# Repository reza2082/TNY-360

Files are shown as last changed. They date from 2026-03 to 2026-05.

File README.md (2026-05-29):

Banner

<div align="center">

# TNY-360 Quadruped Robot





**A compact, open-source robot dog designed to *Understand*, *Interact*, and *Learn*.**

[🌐 Website](https://tny-robotics.com/tny-360) • [📸 Instagram](https://instagram.com/furwaz_) • [💬 Discord](https://discord.gg/XGABkx5A4y) • [📖 Documentation](https://tny-robotics.com/docs/tny-360/)

</div>

---

## 🚀 How to Build Your Own TNY-360

Everything you need to build this robot is 100% free and open-source. Instead of getting lost in the folders, we highly recommend following our official, step-by-step wiki:

<div align="center">

> ### **[👉 START HERE: The Official Step-by-Step Guide 👈](https://tny-robotics.com/docs/tny-360/practical-guide/sourcing)**
> *From ordering the first screw to the assembing the last part, this guide covers it all.*

</div>

### 🗂️ Quick Links (For Advanced Makers)
If you know what you are doing and just want the raw files, here is your toolkit:

* 🛒 **[Bill of Materials (BOM)](https://tny-robotics.com/docs/tny-360/practical-guide/1.sourcing/)** - What to buy, tools needed, and where to find them.
* 📐 **[CAD & 3D Files](./CAD)** - Grab the `.STL` and `.3MF` files for your 3D printer.
* ⚡ **[PCB Designs (Gerbers)](./Electronics/PCBs)** - Files to order the custom PCBs used in the robot.
* 🧠 **[ESP32 Firmware](./Firmware)** - The ESP-IDF C++ firmware & drivers powering the robot.
* 🛠️ **[Servo Modding Tutorial](https://tny-robotics.com/docs/tny-360/anatomy/electronics/mg996r-mod)** - Learn the Op-Amp trick to get position-feedback on MG996R servos.

## ✨ Features

* 🧬 **Dual-Core Architecture:**<br> A segregated system using the ESP32-S3. Core 0 ("Reflex") runs a strict 200Hz kinematics/control loop, while Core 1 ("Brain") handles WebSockets, UI, and orchestration.
* 🔄 **Closed-Loop at 200Hz:**<br> We ditched blind PWM. The TNY-360 uses digital MG996R servos modified with a custom **Op-Amp buffer PCB** for noise-free, high-speed position feedback.
* ⚡ **Zero Cable Spaghetti:**<br> A fully modular hardware ecosystem. Dedicated PCBs (Control, Sensor, Brain, Power, etc.) communicate cleanly via standardized JST-PH cables.
* 🛠️ **Smart Auto-Calibration:**<br> Features mechanical endstops for assembly validation and runtime algorithms that compensate for backlash and actuator latency.
* 🧩 **STEM & Expansion Ready:**<br> Program the robot using [TNY-Coder](https://github.com/TNY-Robotics/TNY-Coder) (our block-based web app) or build custom hardware modules using the dorsal I2C/Power expansion port.
* 🔋 **Industrial Power:**<br> A custom 3S 18650 battery pack capable of 15A continuous discharge, featuring an integrated BMS and Fuse, for 1h+ of runtime.

## 🧠 The Engineering: Beyond a Budget Robot

Most budget quadrupeds suffer from analog noise and jitter when hacking servos for feedback. Simply soldering a wire to a servo's internal potentiometer creates an antenna for EMI and draws current that destabilizes the servo's internal control loop.

**The TNY-360 Solution:** We designed a custom micro-PCB that fits inside the servo, featuring an **Operational Amplifier (Op-Amp) in a voltage follower (buffer) configuration**. 
This provides near-infinite input impedance (zero interference with the motor) and low output impedance to send a clean analog signal over the robot's wiring harness. Coupled with a software low-pass filter, the ESP32 can cleanly poll all 12 legs at 200Hz.

👉 **[Read the full technical deep-dive and the step-by-step Servo Modding Guide on our documentation site.](https://tny-robotics.com/docs/tny-360/anatomy/electronics/mg996r-mod)**

## ⚙️ Hardware Specs

### 🧠 Core & Power
* **MCU:** ESP32-S3 N16R8 Module
* **Power:** 3S LiPo Battery (6x Samsung INR18650-25R)
* **Monitoring:** INA219 (Voltage/Current sensor)

### 🦵 Actuators
* **Legs:** 12x MG996R Servos *(Must be modified for analog feedback)*
* **Head:** 2x SG-90 Micro Servos (Ears)
* **Driver:** PCA9685 (16-Channel PWM)

### 📡 Sensors & I/O
* **Vision:** OV2640 Camera Module
* **Distance:** VL53L0X Time-of-Flight (Lidar)
* **Orientation:** MPU6050 6-axis IMU
* **Display:** SH1106 OLED (128x64)
* **Audio:** I2S MEMS Microphone + Speaker

---

## 📂 Repository Structure

* `BOM/` — **Bill of Materials.** Detailed lists of all components, PCBs, screws, and cables, with links.
* `CAD/` — **Hardware Source.** FreeCAD project files and ready-to-print STLs.
* `Electronics/PCBs/` — **PCB Designs.** Gerber files, BOMs, and Pick'n'Place for all PCBs.
* `Firmware/` — **Codebase.** PlatformIO project (C++/ESP-IDF).
* `Firmware/components/` — **Drivers.** Custom libraries for sensors/actuators.

## 🤝 Contributing

We love contributions!
* **Code:** Please follow the ESP-IDF coding style.
* **Hardware:** Submit PRs with updated FreeCAD files or improvements.
* Found a bug? [Open an Issue](https://github.com/TNY-Robotics/TNY-360/issues).

## 📄 License & Authors

**TNY-360** is maintained by the [TNY Robotics Team](https://tny-robotics.com).

Licensed under **CC BY-NC-SA 4.0**.<br>
*You are free to share and adapt this material for non-commercial purposes, as long as you provide attribution and share alike.*



Need help? Contact us [by mail](mailto:contact@tny-robotics.com) or join our [Discord](https://discord.gg/XGABkx5A4y).

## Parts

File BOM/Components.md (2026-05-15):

# Components

Here's a list of all the components needed to build your TNY-360, and their links!

### Assembly guide

To learn how to fully assemble you TNY-360, check out the [TNY-360 Documentation](http://localhost:3000/docs/tny-360/practical-guide/sourcing/). A more user-friendly list of all the components needed is also available here. 

| Type | Description | Quantity | Location | Link |
| :--- | :--- | :---: | :--- | :--- |
| Step down | DC-DC 300W 20A Buck Converter | 1 | Torso Back | [Click here](https://s.click.aliexpress.com/e/_c3atP8dn) |
| Step down | DC-DC 5V 3A Converter | 1 | Mount PCB | [Click here](https://fr.aliexpress.com/item/1005008678729834.html) \[5V\] |
| | | | | |
| VL53L0X | Laser depth sensor | 1 | Visor | [Click here](https://s.click.aliexpress.com/e/_c4LPbeMT) \[0-200CM\] |
| SH1106 | OLED Screen 64x128 | 1 | Visor | [Click here](https://s.click.aliexpress.com/e/_c4POAdYX) \[WHITE\] |
| TTP223 | Touch sensor | 2 | Visor | [Click here](https://fr.aliexpress.com/item/1005006087171183.html) |
| OV2640 | HD Camera  120° 75mm | 1 | Visor | [Click here](https://s.click.aliexpress.com/e/_c3eXa4EP) \[120°/75mm\] |
| I2S Mic.  | I2S Microphone | 1 | Visor | [Click here](https://s.click.aliexpress.com/e/_c3CFAo5V) |
| Speaker | 2W 8Ω Speaker (25mm x 35mm) | 1 | Head | [Click here](https://fr.aliexpress.com/item/1005008626624201.html) \[5PCS 8Ω 2W\] |
| | | | | |
| SG90 | 0.9kg.cm servomotor | 2 | Head | [Click here](https://s.click.aliexpress.com/e/_c4PiVQKP) \[180°\] |
| MG996R | 12kg.cm servomotor | 12 | Torso / Legs | [Click here](https://s.click.aliexpress.com/e/_c3QXPU2f) \[180°\] |
| | | | | |
| MPU6050 | 6 axis accelerometer & gyroscope | 1 | Torso Center | [Click here](https://s.click.aliexpress.com/e/_c4LXGDrH) |
| Switches  | Tactile switches 6x6x5 mm | 4 | Feet | [Click here](https://s.click.aliexpress.com/e/_c4koO1EL) \[6x6x5mm\] |
| Antenna | Wi-Fi/Bluetooth 2.4Ghz antenna | 1 | Head | [Click here](https://s.click.aliexpress.com/e/_c3wCvBLz) \[FPC-IPX1/5cm] |

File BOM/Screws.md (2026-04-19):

# Screws & Inserts

Here's a list of all screws and inserts needed to build your TNY-360.

A complete kit of M2.5 Screws and Inserts is also linked below for easier sourcing, instead of buying each screws/inserts independently.

### Assembly guide

To learn how to fully assemble you TNY-360, check out the [TNY-360 Documentation](http://localhost:3000/docs/tny-360/practical-guide/sourcing/). A more user-friendly list of all the screws and inserts needed is also available here.

### Screws 

| Type | Length | Quantity | Location | Link |
| :--- | :----- | :---: | :--- | :---: |
| M1.4 | 5 mm | 32 | Shoulder & Knee Servo Disk  | [Click here](https://s.click.aliexpress.com/e/_c3CWv1Vp) |
| | | | | |
| M2.5 | 4 mm | 2 | Torso - PCB Motor Driver | [Click here](https://s.click.aliexpress.com/e/_c3p0AJO3) |
| M2.5 | 4 mm | 2 | Torso - PCB Analog Reader | [Click here](https://s.click.aliexpress.com/e/_c3p0AJO3) |
| M2.5 | 4 mm | 2 | Torso - PCB IMU | [Click here](https://s.click.aliexpress.com/e/_c3p0AJO3) |
| M2.5 | 4 mm | 2 | Torso - PCB Paw Boards | [Click here](https://s.click.aliexpress.com/e/_c3p0AJO3) |
| M2.5 | 4 mm | 4 | Torso - DC-DC Converter | [Click here](https://s.click.aliexpress.com/e/_c3p0AJO3) |
| M2.5 | 10 mm  | 12 | Torso - Top / Bottom screws | [Click here](https://s.click.aliexpress.com/e/_c3p0AJO3) |
| M2.5 | 6 mm | 4 | Torso - Front | [Click here](https://s.click.aliexpress.com/e/_c3p0AJO3) |
| M2.5 | 6 mm | 4 | Torso - Back | [Click here](https://s.click.aliexpress.com/e/_c3p0AJO3) |
| M2.5 | 6 mm | 4 | Torso - Battery | [Click here](https://s.click.aliexpress.com/e/_c3p0AJO3) |
| | | | | |
| M2.5 | 4 mm | 4 | Head - Top | [Click here](https://s.click.aliexpress.com/e/_c3p0AJO3) |
| M2.5 | 4 mm | 4 | Head - Bottom | [Click here](https://s.click.aliexpress.com/e/_c3p0AJO3) |
| M2.5 | 4 mm | 2 | Head - Face Plate | [Click here](https://s.click.aliexpress.com/e/_c3p0AJO3) |
| M2.5 | 4 mm | 4 | Head - PCB | [Click here](https://s.click.aliexpress.com/e/_c3p0AJO3) |
| | | | | |
| M2.5 | 6 mm | 8 | Shoulders - Top | [Click here](https://s.click.aliexpress.com/e/_c3p0AJO3) |
| M2.5 | 4 mm | 2 | Ears - Main Screw | [Click here](https://s.click.aliexpress.com/e/_c3p0AJO3) |
| M2.5 | 4 mm | 3 | Back - PCB | [Click here](https://s.click.aliexpress.com/e/_c3p0AJO3) |
| M2.5 | 4 mm | 4 | Back - Cover | [Click here](https://s.click.aliexpress.com/e/_c3p0AJO3) |
| | | | | |
| M2.5 | 6 mm | 4 | Mount - Cover | [Click here](https://s.click.aliexpress.com/e/_c3p0AJO3) |
| M2.5 | 6 mm | 4 | Mount - Attachment | [Click here](https://s.click.aliexpress.com/e/_c3p0AJO3) |
| M2.5 | 4 mm | 2 | Mount - PCB | [Click here](https://s.click.aliexpress.com/e/_c3p0AJO3) |
| | | | | |
| M2.5 | 4 mm | 6 | Battery - PCB | [Click here](https://s.click.aliexpress.com/e/_c3p0AJO3) |
| M2.5 | 4 mm | 6 | Battery - Cover | [Click here](https://s.click.aliexpress.com/e/_c3p0AJO3) |

### Inserts 

| Type | Length | Quantity | Location | Link |
| :--- | :----- | :---: | :--- | :---: |
| M2.5 | 2 mm | 2 | Torso - PCB Motor Driver | [Click here](https://fr.aliexpress.com/item/1005007653131713.html) |
| M2.5 | 2 mm | 2 | Torso - PCB Analog Reader | [Click here](https://fr.aliexpress.com/item/1005007653131713.html) |
| M2.5 | 2 mm | 2 | Torso - PCB IMU | [Click here](https://fr.aliexpress.com/item/1005007653131713.html) |
| M2.5 | 2 mm | 2 | Torso - PCB Paw Boards | [Click here](https://fr.aliexpress.com/item/1005007653131713.html) |
| M2.5 | 2 mm | 4 | Torso - DC-DC Converter | [Click here](https://fr.aliexpress.com/item/1005007653131713.html) |
| M2.5 | 6 mm | 12 | Torso - Top / Bottom screws | [Click here](https://fr.aliexpress.com/item/1005007653131713.html) |
| M2.5 | 4 mm | 4 | Torso - Front | [Click here](https://fr.aliexpress.com/item/1005007653131713.html) |
| M2.5 | 4 mm | 4 | Torso - Back | [Click here](https://fr.aliexpress.com/item/1005007653131713.html) |
| M2.5 | 2 mm | 4 | Torso - Battery | [Click here](https://fr.aliexpress.com/item/1005007653131713.html) |
| | | | | |
| M2.5 | 2 mm | 4 | Head - Top | [Click here](https://fr.aliexpress.com/item/1005007653131713.html) |
| M2.5 | 2 mm | 4 | Head - Bottom | [Click here](https://fr.aliexpress.com/item/1005007653131713.html) |
| M2.5 | 2 mm | 2 | Head - Face Plate | [Click here](https://fr.aliexpress.com/item/1005007653131713.html) |
| M2.5 | 2 mm | 4 | Head - PCB | [Click here](https://fr.aliexpress.com/item/1005007653131713.html) |
| | | | | |
| M2.5 | 2 mm | 8 | Shoulders - Top | [Click here](https://fr.aliexpress.com/item/1005007653131713.html) |
| M2.5 | 2 mm | 2 | Ears - Main Screw | [Click here](https://fr.aliexpress.com/item/1005007653131713.html) |
| M2.5 | 2 mm | 3 | Back - PCB | [Click here](https://fr.aliexpress.com/item/1005007653131713.html) |
| M2.5 | 2 mm | 4 | Back - Cover | [Click here](https://fr.aliexpress.com/item/1005007653131713.html) |
| | | | | |
| M2.5 | 4 mm | 4 | Mount - Cover | [Click here](https://fr.aliexpress.com/item/1005007653131713.html) |
| M2.5 | 4 mm | 4 | Mount - Attachment | [Click here](https://fr.aliexpress.com/item/1005007653131713.html) |
| M2.5 | 2 mm | 2 | Mount - PCB | [Click here](https://fr.aliexpress.com/item/1005007653131713.html) |
| | | | | |
| M2.5 | 2 mm | 6 | Battery - PCB | [Click here](https://fr.aliexpress.com/item/1005007653131713.html) |
| M2.5 | 2 mm | 6 | Battery - Cover | [Click here](https://fr.aliexpress.com/item/1005007653131713.html) |

### Total 

| Type | Quantity | Link |
| :--- | :---: | --- |
| M1.4 Screw - 5 mm  | 32 | [Click here](https://s.click.aliexpress.com/e/_c3CWv1Vp) |
| | | |
| M2.5 Screw - 4 mm  | 49 | [Click here](https://s.click.aliexpress.com/e/_c3p0AJO3) |
| M2.5 Screw - 6 mm  | 28 | [Click here](https://s.click.aliexpress.com/e/_c3p0AJO3) |
| M2.5 Screw - 10 mm | 12 | [Click here](https://s.click.aliexpress.com/e/_c3p0AJO3) |
| | | |
| M2.5 Insert - 2 mm | 61 | [Click here](https://fr.aliexpress.com/item/1005007653131713.html) |
| M2.5 Insert - 4 mm | 16 | [Click here](https://fr.aliexpress.com/item/1005007653131713.html) |
| M2.5 Insert - 6 mm | 12 | [Click here](https://fr.aliexpress.com/item/1005007653131713.html) |

### Complete kit

To simplify Screws and Inserts sourcing, you can alternatively buy only one complete kit of M2.5 screws and inserts.

* Link to the [Screws / Inserts Kit](https://fr.aliexpress.com/item/1005007830491580.html).

Please check that you selected the `M2.5 500pcs` version before ordering.

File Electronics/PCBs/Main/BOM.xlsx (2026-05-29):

No. | Quantity | Comment | Designator | Footprint | Value | Manufacturer Part | Manufacturer | Supplier Part | Supplier
1 | 1 | XL-5050RGBC-2812B | 2812B | LED-SMD_4P-L5.0-W5.0-BL_XL-5050RGBC |  | XL-5050RGBC-2812B | XINGLIGHT(成兴光) | C2843785 | LCSC
2 | 2 | AMS1117-3.3 | AMS3.3,AMS3.3ESP | SOT-223-3_L6.5-W3.4-P2.30-LS7.0-BR |  | AMS1117-3.3 | AMS | C6186 | LCSC
3 | 2 | B3B-PH-K-S(LF)(SN) | BTN_LEFT,BTN_RIGHT | CONN-TH_B3B-PH-K-S |  | B3B-PH-K-S(LF)(SN) | JST | C131339 | LCSC
4 | 1 | HX 0.5-24PIN XGXJ-H2.0 | CAM | FPC-SMD_24P-P0.50_HX-0.5-24PIN-XGXJ-H2.0 |  | HX 0.5-24PIN XGXJ-H2.0 | hanxia(韩下) | C19269981 | LCSC
5 | 3 | 220pF | CASIG,CSPKRG,CSPKRV | C0603 | 220pF | CL10B221KB8NNNC | SAMSUNG(三星) | C1603 | LCSC
6 | 4 | 10uF | CAVDD2,CCH340,CDVDD2,CESP2 | C0603 | 10uF | CL10A106MA8NRNC | SAMSUNG(三星) | C96446 | LCSC
7 | 8 | 100nF | CAVDD,CAVDD1,CCAM14,CCSI_RST,CDVDD1,CESP1,CINL,CSPKR | C0603 | 100nF | CC0603KRX7R9BB104 | YAGEO(国巨) | C14663 | LCSC
8 | 1 | 15pF | CCAM8 | C0603 | 15pF | CL10C150JB8NNNC | SAMSUNG(三星) | C1644 | LCSC
9 | 1 | CH340C | CH340C | SOP-16_L10.0-W3.9-P1.27-LS6.0-BL |  | CH340C | WCH(南京沁恒) | C84681 | LCSC
10 | 3 | 1uF | CINR1,CUPEN1,CVREF | C0603 | 1uF | CL10A105KO8NNNC | SAMSUNG(三星) | C1592 | LCSC
11 | 1 | 10nF | CINR2 | C0603 | 10nF | 0603B103K500NT | FH(风华) | C57112 | LCSC
12 | 4 | B4B-PH-K-S(LF)(SN) | CN-BAT,CN-IMU,CN-LASER,CN-SCREEN | CONN-TH_B4B-PH-K-S |  | B4B-PH-K-S(LF)(SN) | JST | C131334 | LCSC
13 | 2 | B5B-PH-K-S(LF)(SN) | CN-MOTORS,MIC | CONN-TH_B5B-PH-K-S-LF-SN |  | B5B-PH-K-S(LF)(SN) | JST | C157993 | LCSC
14 | 1 | B2B-PH-K-S(LF)(SN) | CN-POWER | CONN-TH_B2B-PH-K-S |  | B2B-PH-K-S(LF)(SN) | JST | C131337 | LCSC
15 | 1 | B7B-PH-K-S(LF)(SN) | CN-READER | CONN-TH_B7B-PH-K-S-LF-SN |  | B7B-PH-K-S(LF)(SN) | JST | C157981 | LCSC
16 | 1 | 470uF | CPGND | CAP-TH_BD8.0-P3.50-D0.6-FD | 470uF | GR477M025F14RR0VL4FP0 | Chengx(承兴) | C5154 | LCSC
17 | 2 | SS34 | D1,D2 | SMA_L4.3-W2.6-LS5.2-RD |  | SS34 | MDD(辰达半导体) | C8678 | LCSC
18 | 1 | SMAJ5.0A | D3 | SMA_L4.3-W2.6-LS5.2-RD |  | SMAJ5.0A | RUILON(瑞隆源) | C10758 | LCSC
19 | 1 | ESP32-S3-WROOM-1U-N16R8 | ESP32-S3 | WIRELM-SMD_ESP32-S3-WROOM-1U |  | ESP32-S3-WROOM-1U-N16R8 | ESPRESSIF(乐鑫) | C3013946 | LCSC
20 | 1 | SMD1812P150TF/16 | F1 | F1812 |  | SMD1812P150TF/16 | RUILON(瑞隆源) | C20810 | LCSC
21 | 3 | BLM18SG121TN1D | LAVDD,LSPKRG,LSPKRV | L0603 |  | BLM18SG121TN1D | muRata(村田) | C113030 | LCSC
22 | 1 | PAM8406DR | PAM8406 | SOIC-16_L9.9-W3.9-P1.27-LS6.0-BL |  | PAM8406DR | DIODES(美台) | C86270 | LCSC
23 | 2 | S8050 J3Y(RANGE:200-350) | QDTR,QRTS | SOT-23-3_L3.0-W1.7-P0.95-LS2.9-BR |  | S8050 J3Y(RANGE:200-350) | CJ(江苏长电/长晶) | C2146 | LCSC
24 | 2 | 1kΩ | RCAM17,RINR | R0603 | 1kΩ | RC0603FR-071KL | YAGEO(国巨) | C22548 | LCSC
25 | 3 | 10kΩ | RDTR,RRTS,RUPEN1 | R0603 | 10kΩ | 0603WAF1002T5E | UNI-ROYAL(厚声) | C25804 | LCSC
26 | 1 | 22kΩ | RPAM | R0603 | 22kΩ | 0603WAF2202T5E | UNI-ROYAL(厚声) | C31850 | LCSC
27 | 1 | 4.7kΩ | RRST | R0603 | 4.7kΩ | 0603WAF4701T5E | UNI-ROYAL(厚声) | C23162 | LCSC
28 | 4 | 2.2kΩ | RUPFA,RUPFL,RUPSA,RUPSL | R0603 | 2.2kΩ | 0603WAF2201T5E | UNI-ROYAL(厚声) | C4190 | LCSC
29 | 1 | 1.25mm-2P ZZ-MS | SPEAKER | CONN-TH_2P-P1.25_1.25MM-2P-ZZ-MS |  | 1.25mm-2P ZZ-MS | SHOU HAN(首韩) | C5368706 | LCSC
30 | 1 | TYPE-C16PIN | USB | USB-C-SMD_TYPE-C16PIN |  | TYPE-C16PIN | SHOU HAN(首韩) | C393939 | LCSC
31 | 1 | USBLC6-2SC6 | USBLC6 | SOT-23-6_L2.9-W1.6-P0.95-LS2.8-BL |  | USBLC6-2SC6 | ST(意法半导体) | C7519 | LCSC
32 | 1 | XC6206-1.2V | XC6206-1.2 | SOT-23-3_L3.0-W1.6-P1.90-LS2.8-BR |  | XC6206-1.2V | YONGYUTAI(永裕泰) | C49446790 | LCSC
33 | 1 | XC6206-2.8V | XC6206-2.8 | SOT-23-3_L2.9-W1.6-P1.90-LS2.8-BR |  | XC6206-2.8V | YONGYUTAI(永裕泰) | C2892669 | LCSC

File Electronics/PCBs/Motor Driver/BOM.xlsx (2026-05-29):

No. | Quantity | Comment | Designator | Footprint | Value | Manufacturer Part | Manufacturer | Supplier Part | Supplier
1 | 2 | 100nF | C-LS,C-PCA | C0805 | 100nF | CC0805KRX7R9BB104 | YAGEO(国巨) | C49678 | LCSC
2 | 4 | B3B-PH-K-S(LF)(SN) | CN-BL,CN-BR,CN-FL,CN-FR | CONN-TH_B3B-PH-K-S |  | B3B-PH-K-S(LF)(SN) | JST | C131339 | LCSC
3 | 1 | B5B-PH-K-S(LF)(SN) | CN-SIGNAL | CONN-TH_B5B-PH-K-S-LF-SN |  | B5B-PH-K-S(LF)(SN) | JST | C157993 | LCSC
4 | 1 | PCA9306DCUR | PCA9306 | SSOP-8_L2.0-W2.3-P0.50-LS3.1-BR |  | PCA9306DCUR | TI(德州仪器) | C33196 | LCSC
5 | 1 | PCA9685PW,118 | PCA9685 | TSSOP-28_L9.7-W4.4-P0.65-LS6.4-TL | - | PCA9685PW,118 | NXP(恩智浦) | C2678753 | LCSC
6 | 14 | 220Ω | R1,R2,R3,R4,R5,R6,R7,R8,R9,R10,R11,R12,R13,R14 | R0805 | 220Ω | 0805W8F2200T5E | UNI-ROYAL(厚声) | C17557 | LCSC
7 | 1 | 200kΩ | R-LS | R0805 | 200kΩ | 0805W8F2003T5E | UNI-ROYAL(厚声) | C17539 | LCSC
8 | 2 | 2.2kΩ | RUP1,RUP2 | R0805 | 2.2kΩ | 0805W8F2201T5E | UNI-ROYAL(厚声) | C17520 | LCSC

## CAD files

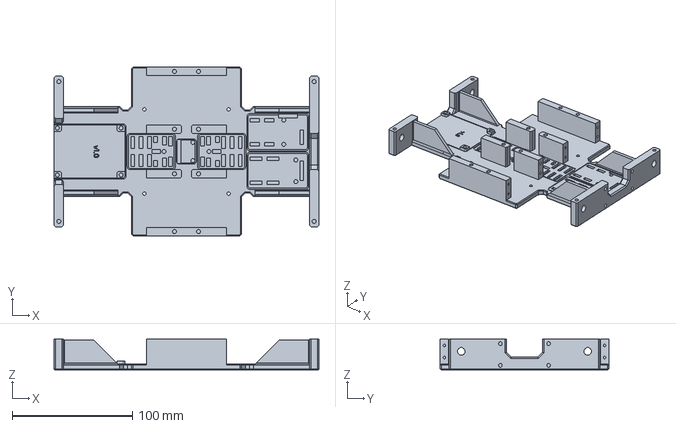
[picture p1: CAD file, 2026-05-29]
CAD/01_Parts/Torso.FCStd
220.0 x 140.0 x 25.7 mm

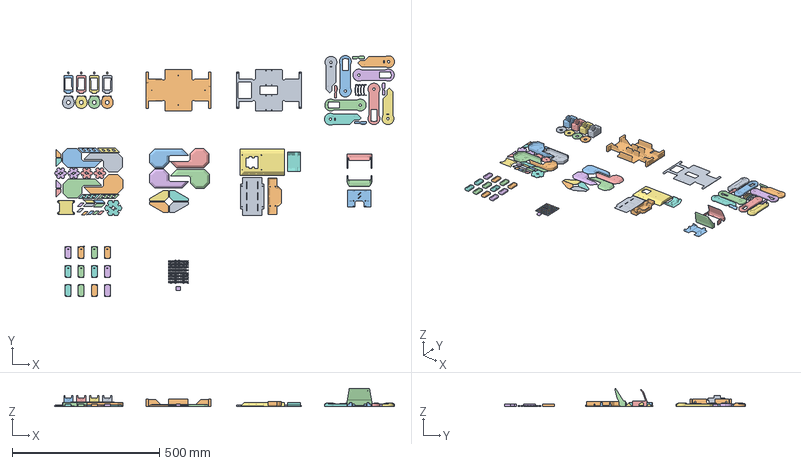
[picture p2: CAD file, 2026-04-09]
CAD/Exported/TNY-360.3mf
1152.9 x 816.7 x 62.4 mm
Shoulder - BL.stl
Servo - Cover Top.stl x 8
Clip.stl x 72
Shoulder - BR.stl
Shoulder - FL.stl
Servo - Cover Right.stl x 2
Shoulder - FR.stl
Servo - Cover Left.stl x 2
Shoulder - Top.stl x 4
Shoulder - Pin.stl x 4
Torso - Top.stl
Torso - Bottom.stl
Leg - Top BL.stl
Leg - Top BR.stl
Leg - Top FL.stl
Leg - Top FR.stl
Leg - Bottom L.stl x 2
Leg - Bottom R.stl x 2
Leg - Top Cover Top L.stl x 2
Leg - Top Cover Top R.stl x 2
Leg - Bottom L - Cover.stl x 2
Leg - Bottom R - Cover.stl x 2
Leg - Top Cover Bottom L.stl x 2
Leg - Top Cover Bottom R.stl x 2
Leg - Top Cover Logo L.stl x 2
Leg - Top Cover Logo R.stl x 2
Leg - Top Cover Stripes L.stl x 2
Leg - Top Cover Stripes R.stl x 2
Leg - Bottom L - Cover Black 1.stl x 2
Leg - Bottom L - Cover Black 2.stl x 2
Leg - Bottom R - Cover Black 1.stl x 2
Leg - Bottom R - Cover Black 2.stl x 2
Torso - Cover.stl
Torso - Cover Logo.stl
Torso - Cover Wing.stl x 6
Torso - Cover Attach.stl
Back - Bottom Clip.stl
Battery - LipoHolder Base.stl
Back - Cover.stl
Head - Backplate.stl
Head - Bottom Cover.stl
Head - Top Cover.stl
Clip - Helper.stl
Leg - Top Wire holder.stl x 4
Leg - Top Wire Holder L.stl x 2
Leg - Top Wire Holder R.stl x 2

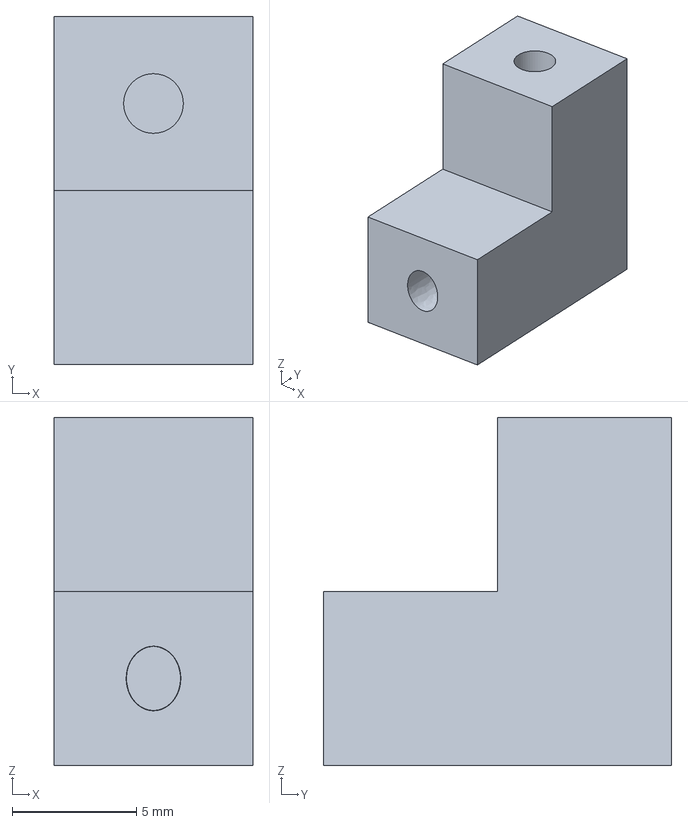
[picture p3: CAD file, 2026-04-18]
CAD/Settings.FCStd
8.00 x 14.0 x 14.0 mm

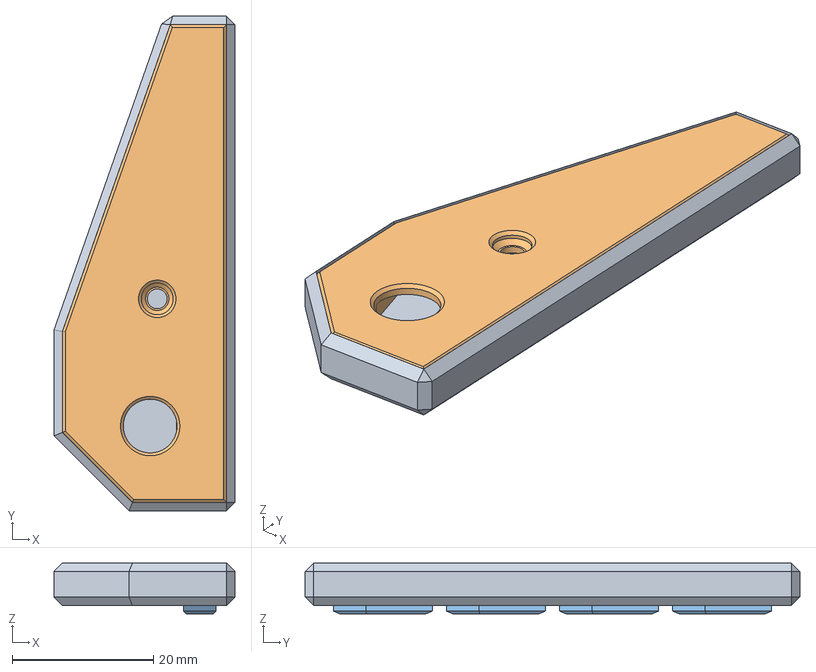
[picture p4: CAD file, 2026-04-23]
CAD/01_Parts/Ears.FCStd
25.6 x 70.0 x 7.20 mm
Front - L
Back - L
Deco - L

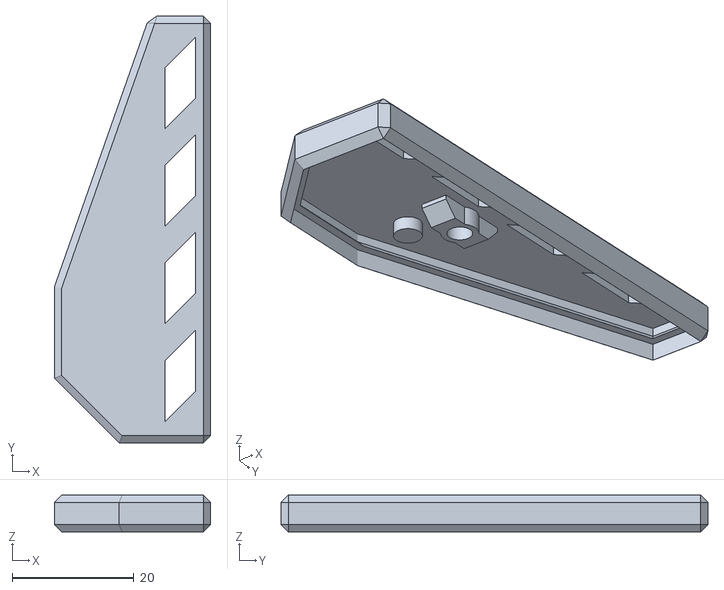
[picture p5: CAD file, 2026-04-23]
CAD/Exported/STLs/Ears - Front R.stl
25.6 x 70.0 x 6.00

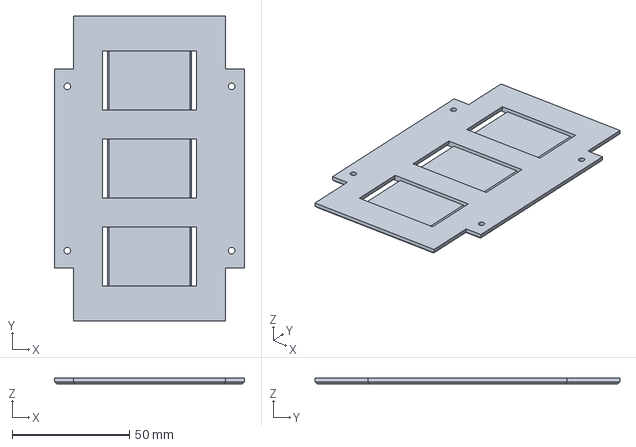
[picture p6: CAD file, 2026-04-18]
CAD/01_Parts/Battery.FCStd
81.0 x 130.0 x 2.40 mm

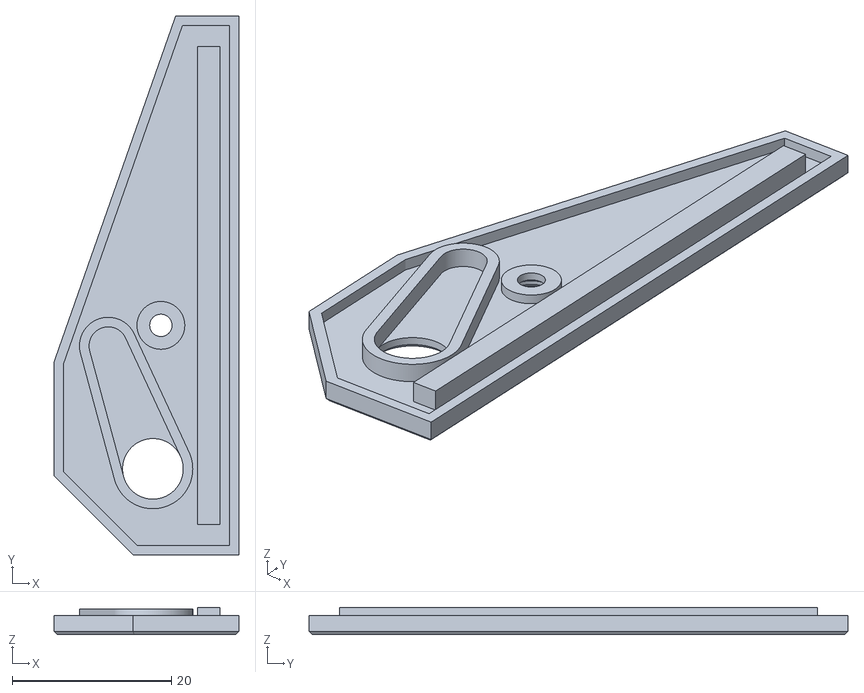
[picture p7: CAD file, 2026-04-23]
CAD/Exported/STLs/Ears - Back R.stl
23.2 x 67.6 x 3.40

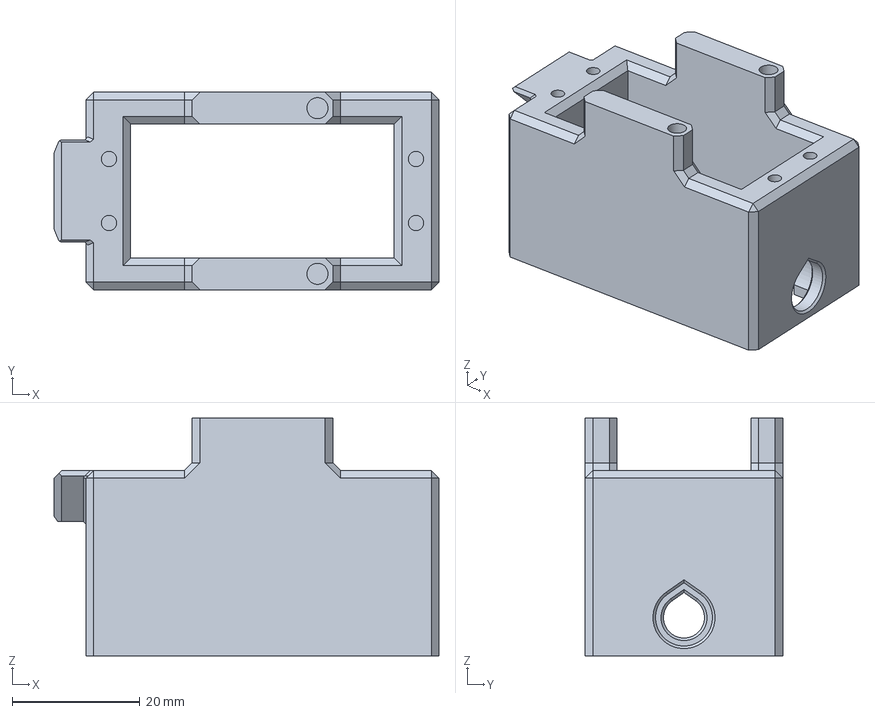
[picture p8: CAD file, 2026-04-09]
CAD/01_Parts/Shoulders.FCStd
60.2 x 30.9 x 37.2 mm

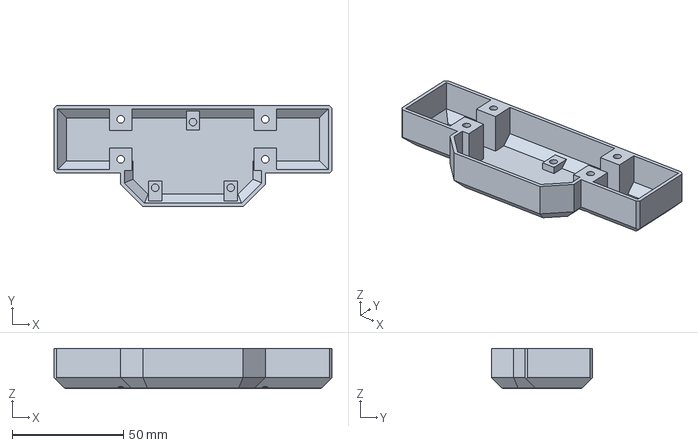
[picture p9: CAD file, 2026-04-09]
CAD/01_Parts/Back.FCStd
125.0 x 45.5 x 18.1 mm

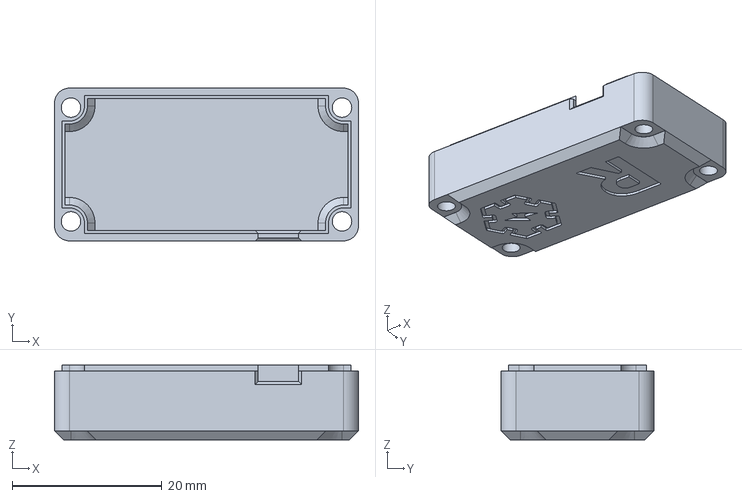
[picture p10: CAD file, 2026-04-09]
CAD/01_Parts/Servo_Cover.FCStd
40.6 x 20.4 x 10.0 mm

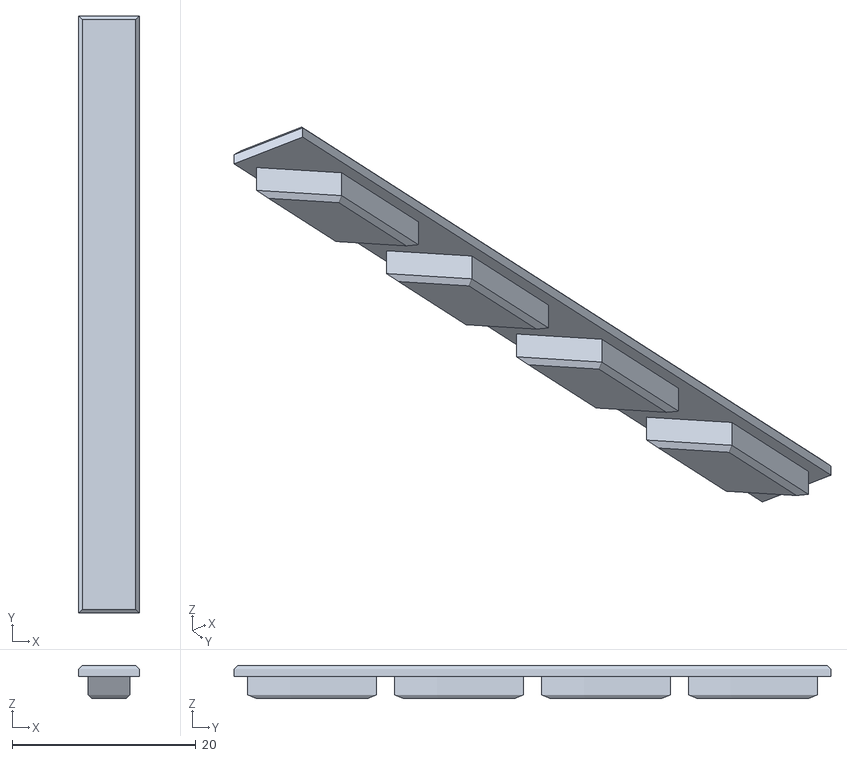
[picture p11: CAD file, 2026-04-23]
CAD/Exported/STLs/Ears - Deco L.stl
6.60 x 65.0 x 3.60

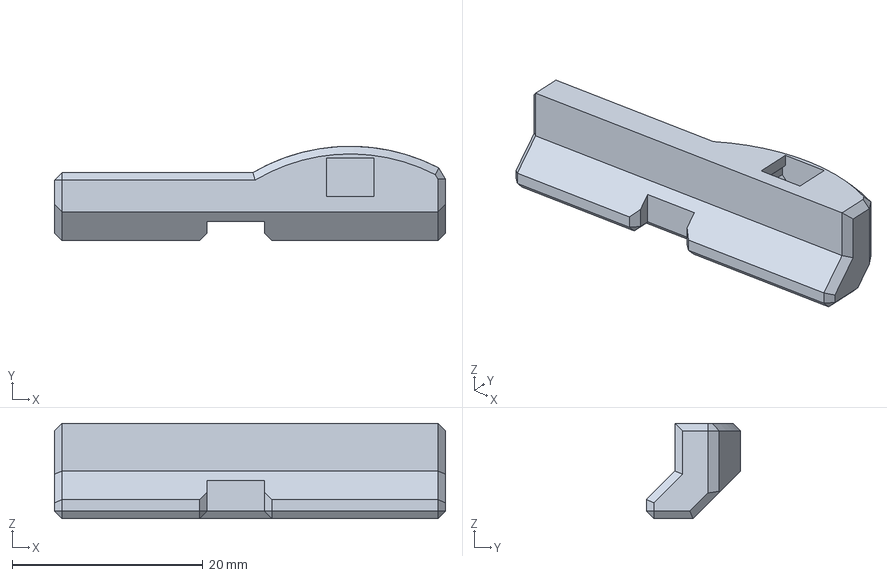
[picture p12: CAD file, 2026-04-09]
CAD/01_Parts/Leg_Top.FCStd
41.0 x 9.90 x 10.0 mm

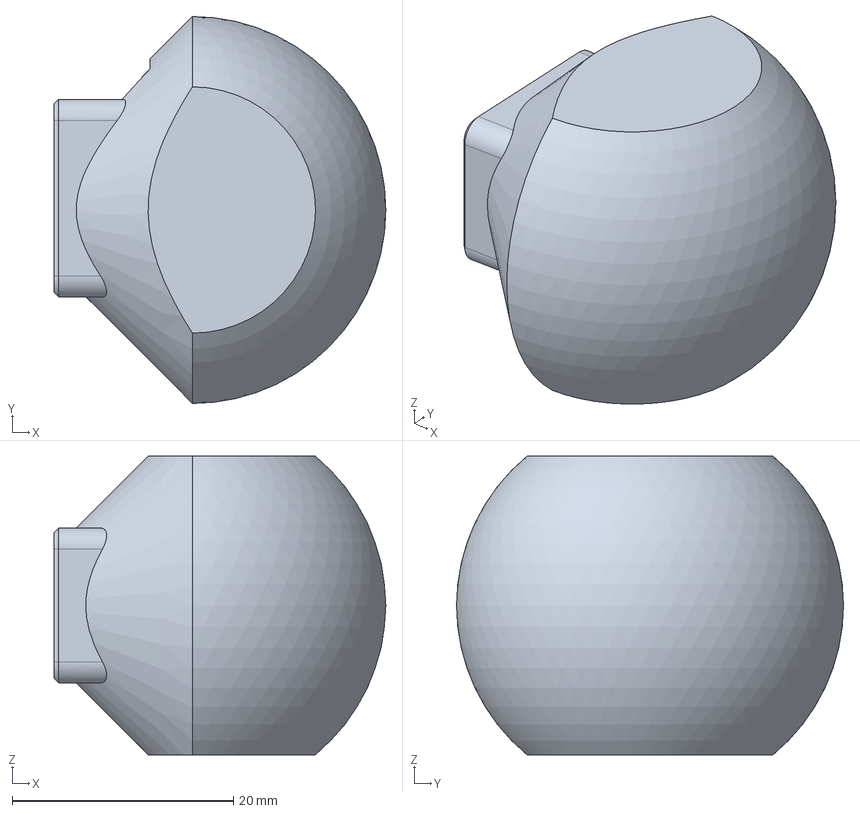
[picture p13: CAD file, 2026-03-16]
CAD/01_Parts/Leg_Bottom.FCStd
30.0 x 35.0 x 27.0 mm

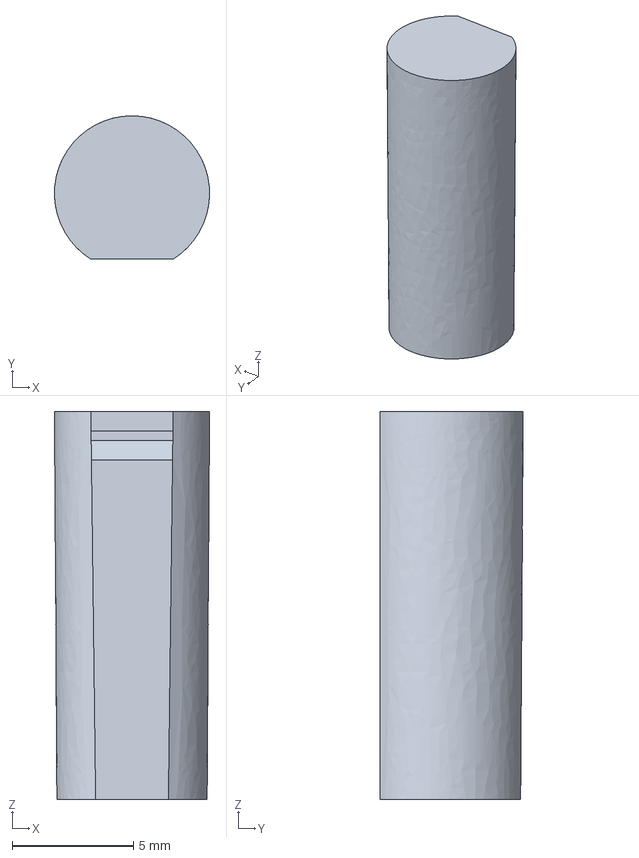
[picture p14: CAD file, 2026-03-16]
CAD/01_Parts/Torso-Shoulder_Pin.FCStd
6.40 x 5.91 x 16.0 mm

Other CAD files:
CAD/Exported/STLs/Torso - Bottom.stl
CAD/Exported/STLs/Ears - Back L.stl
CAD/Exported/STLs/Ears - Front L.stl
CAD/Exported/STLs/Ears - Deco R.stl
CAD/Exported/STLs/Settings - ServoScrew.stl

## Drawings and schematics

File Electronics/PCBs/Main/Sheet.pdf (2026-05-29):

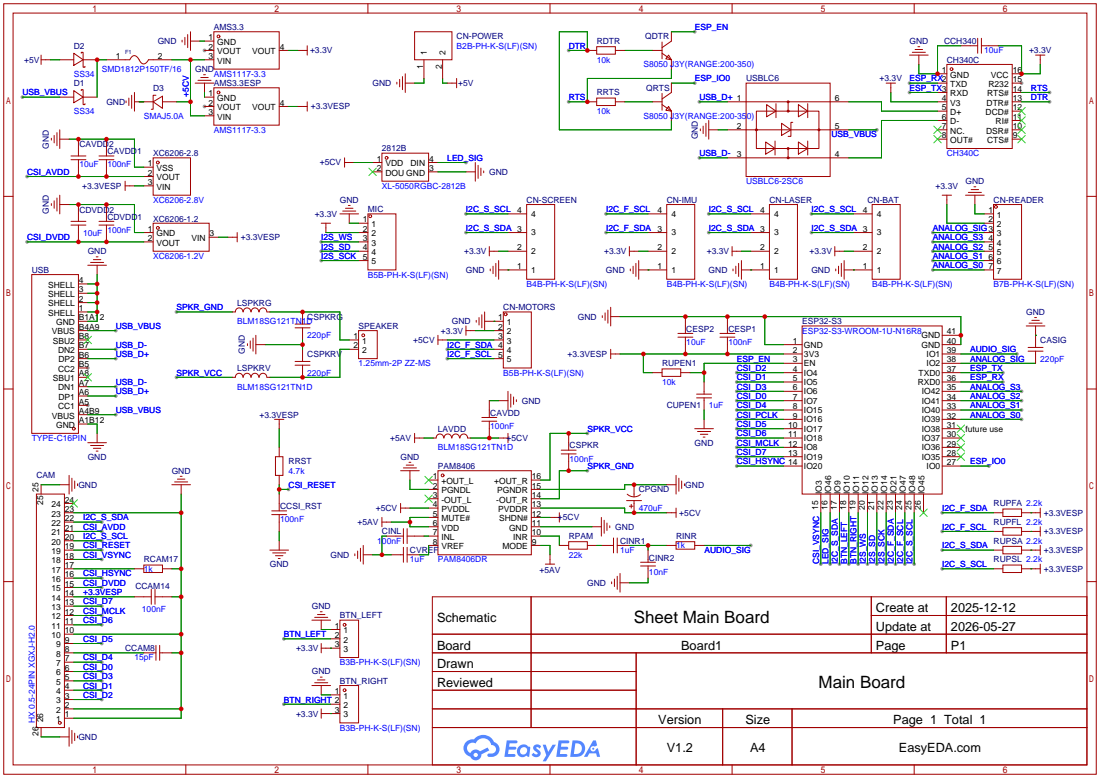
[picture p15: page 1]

DSR# 10 RI# 11 DCD# 12 DTR# 13 RTS# 14 R232 15 VCC 16

INR 10 GND 11 SHDN# 12 PVDDR 13 -OUT_R 14 PGNDR 15 +OUT_R 16

Schematic | Sheet Main Board | Create at | 2025-12-12

Update at | 2026-05-27

Board | Board1 | Page | P1
Drawn | | Main Board
Reviewed

Version | Size | Page 1 Total 1
V1.2 | A4 | EasyEDA.com

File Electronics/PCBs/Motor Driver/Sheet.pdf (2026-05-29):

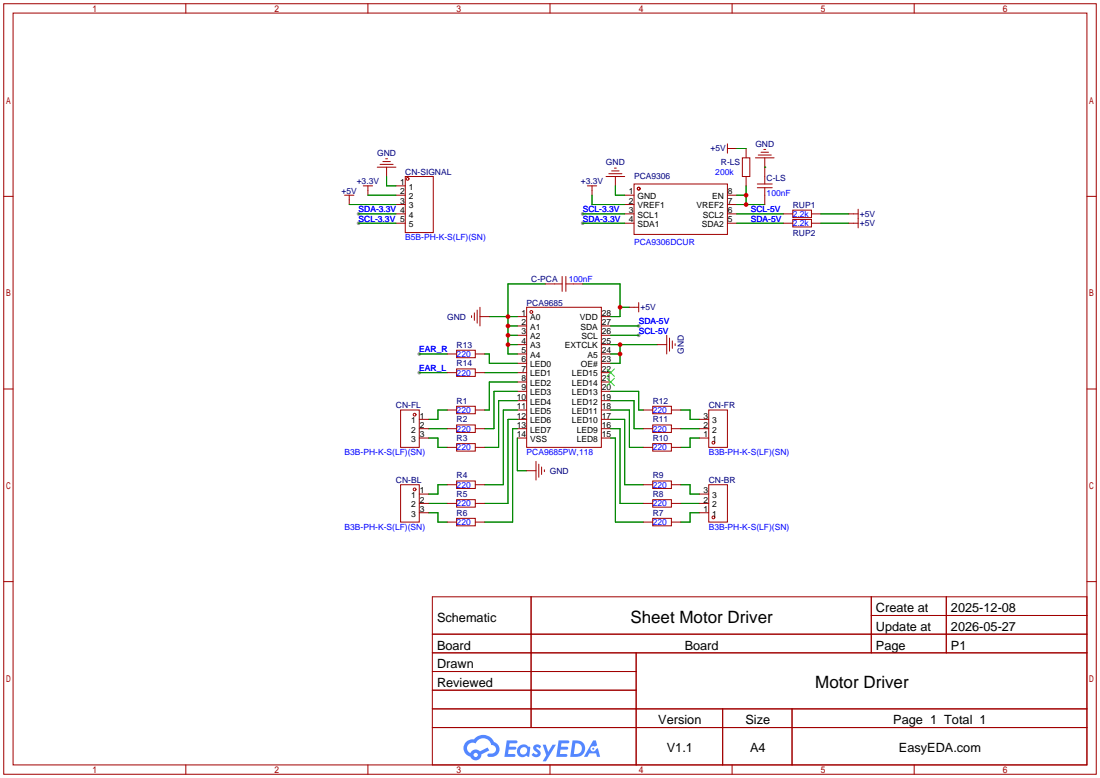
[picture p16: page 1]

Schematic | Sheet Motor Driver | Create at | 2025-12-08

Update at | 2026-05-27

Board | Board | Page | P1
Drawn | | Motor Driver
Reviewed

Version | Size | Page 1 Total 1
V1.1 | A4 | EasyEDA.com

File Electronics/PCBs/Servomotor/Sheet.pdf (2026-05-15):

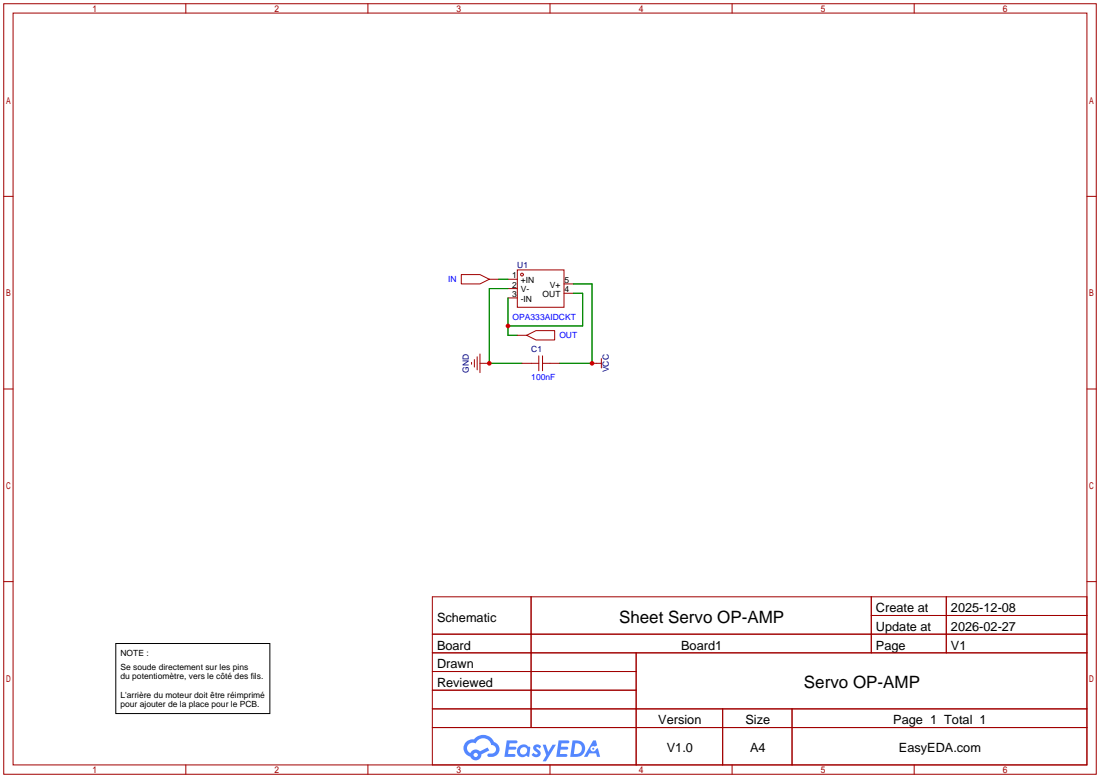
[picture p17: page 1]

Schematic | Sheet Servo OP-AMP | Create at | 2025-12-08

Update at | 2026-02-27

Board | Board1 | Page | V1
Drawn | | Servo OP-AMP
Reviewed

NOTE :
Se soude directement sur les pins
du potentiomètre, vers le côté des fils.
L'arrière du moteur doit être réimprimé
pour ajouter de la place pour le PCB.

Version | Size | Page 1 Total 1
V1.0 | A4 | EasyEDA.com

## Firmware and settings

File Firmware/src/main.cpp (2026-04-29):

#include <freertos/FreeRTOS.h>
#include "common/Log.hpp"
#include "Robot.hpp"
#include "common/config.hpp"
#include "audio/WavProvider.hpp"
#include "audio/SineProvider.hpp"
#include "drivers/CameraDriver.hpp"
#include "boot/BootManager.hpp"

static const char* TAG = "Main";

static Robot robot;
CameraDriver cam;
WiFiManager wifi;

#ifdef __cplusplus
extern "C" {
#endif
void app_main()
{
    // wifi.init();
    
    // vTaskDelay(pdMS_TO_TICKS(2000));

    // cam.init();

    // return;

    // Check for special boot state (zero-calibration, pending update, etc.)
    if (BootManager::CheckForSpecialBoot())
    {
        // Special boot state detected.
        // The corresponding boot will be handled by the BootManager.
        // just return to avoid booting as normal (should not happen anyway)
        return;
    }

    LOG_INFO(TAG, "Initializing robot (FIRMWARE_VERSION=%s) ...", FIRMWARE_VERSION);

    if (Error err = robot.init(); err != Error::None)
    {
        LOG_ERROR(TAG, "Failed to initialize robot. Error : %s", ErrorToString(err));
        return;
    }

    LOG_INFO(TAG, "Robot initialized successfully.");
    
    LOG_INFO(TAG, "Starting robot ...");

    if (Error err = robot.start(); err != Error::None)
    {
        LOG_ERROR(TAG, "Failed to start robot. Error : %s", ErrorToString(err));
        return;
    }

    LOG_INFO(TAG, "Robot started successfully !");

    LOG_INFO(TAG, "Enabling body motors.");
    if (Error err = robot.getBody().enable(); err != Error::None)
    {
        LOG_ERROR(TAG, "Failed to enable body motors. Error: %s", ErrorToString(err));
        return;
    }

    // clamping joint velocity to stand up (safety measure)
    Joint::ClampVelocity(0.5f); // rad/s

    Transformf stand_position{
        Vec3f{0.f, 0.f, DEFAULT_BODY_HEIGHT_M},
        Quatf{}
    };
    Robot::GetInstance().getDecisionLoop().setBodyTransform(stand_position);
    robot.getBody().getLeftEar().applyCommand(DEG_TO_RAD(45.f), 0); // TODO : Use joint override
    robot.getBody().getRightEar().applyCommand(DEG_TO_RAD(45.f), 0); // TODO : Use joint override

    // wait a bit for the robot to stand up
    vTaskDelay(pdMS_TO_TICKS(4000));

    // Reset joint velocity clamping and we're ready to go!
    Joint::ClampVelocity(Joint::MAX_VELOCITY_RAD_S); // could also set to 0 to disable clamping, either way works
    
    LOG_INFO(TAG, ">>> Robot is operational.");
}
#ifdef __cplusplus
}
#endif

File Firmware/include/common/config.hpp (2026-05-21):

#pragma once
#include <cstdint>
#include <driver/gpio.h>

/** COMPILATION FLAGS **/
#define DEBUG_MODE 1  // 1 to enable debug logs and behaviors, 0 to disable

/** MULTICORE SETUP */
constexpr int CORE_BRAIN = 0;
constexpr int CORE_REFLEX = 1;
// number of milliseconds before triggering security stop (in case brain core crashes, to clear control intent)
constexpr uint32_t CONTROL_INTENT_WATCHDOG_MS = 500;

/** OTA SETUP **/
constexpr const char* OTA_FIRMWARE_LATEST_URL = "https://api.tny-robotics.com/firmware/latest";
constexpr const char* OTA_FILESYSTEM_DOWNLOAD_URL = "https://cdn.tny-robotics.com/firmware/tny-360/%s/filesystem.bin";
constexpr int OTA_UPDATE_TIMEOUT_MS = 5000;
constexpr int OTA_UPDATE_FILESYSTEM_BUFFER_SIZE = 4096; // in bytes
constexpr const char* OTA_ROBOT_MODEL = "tny-360";


/** PHYSICAL INFORMATIONS **/
constexpr float LEG_THIGH_LENGTH_M = 0.100f; // in meters
constexpr float LEG_CALF_LENGTH_M = 0.100f; // in meters
constexpr float HIP_OFFSET_M = 0.034f; // in meters
constexpr float HIP_POS_X_M = 0.086f; // in meters, from body center
constexpr float HIP_POS_Y_M = 0.052f; // in meters, from body center

/** DEFAULT POSE INFORMATIONS **/
constexpr float DEFAULT_BODY_HEIGHT_M   = 0.120f; // in meters, from ground level
constexpr float DEFAULT_FEET_SPREAD_X_M = 0.090f; // in meters, from body center
constexpr float DEFAULT_FEET_SPREAD_Y_M = 0.100f; // in meters, from body center


/** LOGGING **/
// Maximum number of log lines to store
constexpr int LOG_MAX_LINES = 20;
// Maximum length of each log message
constexpr int LOG_MAX_MSG_LEN = 256;

/** FILESYSTEM **/
// Maximum path length for file operations
constexpr int MAX_PATH_LEN = 128;

/** RPC **/
constexpr int RPC_QUEUE_SIZE = 32; // number of pending RPC jobs (between core 0 and core 1)


/** Wi-Fi **/
// Maximum number of connection retries before giving up
constexpr uint8_t WIFI_MAX_RETRIES = 5;
// Maximum length for SSID and Password
constexpr uint8_t WIFI_MAX_SSID_LEN = 32;
constexpr uint8_t WIFI_MAX_PASSWORD_LEN = 64;
// AP SSID and Password
constexpr const char* WIFI_AP_SSID = "TNY-360";
constexpr const char* WIFI_AP_PASSWORD = ""; // open by default


/** Websocket **/
// Maximum message size for WebSocket frames
constexpr uint16_t WEBSOCKET_MAX_MSG_SIZE = 256; // in bytes


/** Protocol **/
// Maximum number of pending protocol commands
constexpr uint8_t PROTOCOL_MAX_PENDING_COMMANDS = 32;
// Maximum number of commands in the protocol
constexpr uint8_t PROTOCOL_MAX_COMMANDS_HANDLERS = 255;


/** I2C **/
// Primary I2C GPIO pins (for critical modules, like sensors)
constexpr gpio_num_t I2C_PRIMARY_SDA_GPIO_NUM = GPIO_NUM_21;
constexpr gpio_num_t I2C_PRIMARY_SCL_GPIO_NUM = GPIO_NUM_47;
// Secondary I2C GPIO pins (for less critical modules, like screens)
constexpr gpio_num_t I2C_SECONDARY_SDA_GPIO_NUM = GPIO_NUM_9;
constexpr gpio_num_t I2C_SECONDARY_SCL_GPIO_NUM = GPIO_NUM_48;


/** Analog Readings **/
// EMA filter alpha value (1.0 = no filtering, 0.1 = big inertia)
constexpr float ANALOG_EMA_ALPHA = 0.05f;

/** Timer management **/
// Control loop frequency
constexpr int CONTROL_LOOP_FREQ_HZ = 200; // Hz
// Resolution of the control loop timer
constexpr int TIMER_RESOLUTION = 1'000'000; // 1Mhz, 1 us
// [][] calculated values below, do not edit manually
constexpr int TIMER_ALARM_COUNT = TIMER_RESOLUTION / CONTROL_LOOP_FREQ_HZ;
constexpr float CONTROL_LOOP_DT_S = 1.0f / CONTROL_LOOP_FREQ_HZ;
constexpr int CONTROL_LOOP_DT_MS = static_cast<int>(CONTROL_LOOP_DT_S * 1000);

// Decision loop frequency
constexpr int DECISION_LOOP_FREQ_HZ = 10; // Hz
constexpr float DECISION_LOOP_DT_S = 1.0f / DECISION_LOOP_FREQ_HZ;
constexpr int DECISION_LOOP_DT_MS = static_cast<int>(DECISION_LOOP_DT_S * 1000);

/** Analog scanner **/
// GPIO pins for the 4-bit multiplexer select lines
constexpr gpio_num_t SCANNER_SLCT_PIN1 = GPIO_NUM_39;
constexpr gpio_num_t SCANNER_SLCT_PIN2 = GPIO_NUM_40;
constexpr gpio_num_t SCANNER_SLCT_PIN3 = GPIO_NUM_41;
constexpr gpio_num_t SCANNER_SLCT_PIN4 = GPIO_NUM_42;


/** LEG **/
// Voltage threshold at which the leg is considered as grounded (touching ground)
constexpr float LEG_GROUNDED_THRESHOLD_V = 2.0f;


/** IMU **/
// I2C address for the IMU (MPU6050)
constexpr uint8_t IMU_I2C_ADDR = 0x68;
// I2C clock speed for IMU communication
constexpr uint32_t IMU_I2C_CLOCK = 100000; // 100kHz, could be up to 400kHz but i'm not 100% confident in the wiring
// number of samples to gather for calibration
constexpr uint16_t IMU_NB_CALIB_SAMPLES = 100;
// NOTE : Internal robot imu update is driven by the main timer at 200Hz
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

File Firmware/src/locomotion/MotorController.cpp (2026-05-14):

#include "locomotion/MotorController.hpp"
#include "common/Log.hpp"
#include "Robot.hpp"
#include <cstdio>

constexpr const char* TAG = "MotorController";

MotorController::MotorController() {}

MotorController::MotorController(MotorDriver::Channel motor_channel, AnalogDriver::Channel analog_channel, MotorAttributes attribs)
    : motor_channel(motor_channel),
      analog_channel(analog_channel),
      motor_attributes(attribs),
      calibration_state(CalibrationState::UNCALIBRATED),
      state(State::DISABLED),
      target_position(0.5f),
      nvshandle_ptr(nullptr)
{
    // set default pwm bounds to motor attributes
    calibration_data.pwm_min = motor_attributes.pwm_min;
    calibration_data.pwm_max = motor_attributes.pwm_max;
    disable(); // make sure motor is off by default
}

Error MotorController::init()
{
    // Check if below drivers are initialized
    LOG_SCOPE(TAG, "MotorController::init [driver=%u, reader=%u]", motor_channel, analog_channel);

    if (Error err = MotorDriver::Init(); err != Error::None)
    {
        state = State::ERROR;
        return err;
    }
    if (Error err = AnalogDriver::Init(); err != Error::None)
    {
        state = State::ERROR;
        return err;
    }

    // Try to read calibration data from NVS
    if (Error err = NVS::Init(); err != Error::None)
    {
        state = State::ERROR;
        return err;
    }
    char key[32]; // using motorChannel as identifier
    sprintf(key, "MtrCtrl-%d", static_cast<int>(motor_channel));
    if (Error err = NVS::Open(key, &nvshandle_ptr); err != Error::None)
    {
        state = State::ERROR;
        LOG_ERROR(TAG, "Failed to open NVS handle for motor channel %d with error [%s]", motor_channel, ErrorToString(err));
        ErrorHandle(ErrorStruct::MotorControllerInitFailed);
        return err;
    }
    if (nvshandle_ptr->get("calib_data", calibration_data) == Error::None)
    {
        LOG_INFO(TAG, "Calibration data loaded from NVS for motor channel %d", motor_channel);
        state = State::ENABLED;
        calibration_state = CalibrationState::CALIBRATED;
    }
    else
    {
        LOG_WARNING(TAG, "No calibration data found");
        calibration_state = CalibrationState::UNCALIBRATED;
    }

    // Disable motor initially
    disable();
    
    return Error::None;
}

Error MotorController::deinit()
{
    if (nvshandle_ptr)
    {
        NVS::Close(nvshandle_ptr);
        nvshandle_ptr = nullptr;
    }

    return Error::None;
}

Error MotorController::enable()
{
    state = State::ENABLED;
    __send_target_position(); // effective right now
    return Error::None;
}

Error MotorController::disable()
{
    state = State::DISABLED;
    __send_target_position(); // effective right now
    return Error::None;
}

Error MotorController::startCalibration()
{
    LOG_INFO(TAG, "Starting motor calibration");

    if (calibration_state == CalibrationState::CALIBRATING)
    {
        LOG_WARNING(TAG, "Motor is already in calibration mode");
        return Error::InvalidState;
    }

    if (BaseType_t err = xTaskCreatePinnedToCore([](void* param) {
            // Stop the control loop and take over for the calibration
            ControlLoop& ctrl = Robot::GetInstance().getControlLoop();
            bool wasRunning = ctrl.isRunning();
            if (wasRunning)
            {
                LOG_DEBUG(TAG, "Disabling control loop");
                if (Error err = ctrl.stop(); err != Error::None)
                {
                    LOG_ERROR(TAG, "Failed to stop control loop for motor calibration. Error [%s]", ErrorToString(err));
                    return;
                }
            }

            MotorController* controller = static_cast<MotorController*>(param);
            controller->calibration_state = CalibrationState::CALIBRATING;
            Error err = controller->run_calibration_sequence();
            if (err != Error::None)
            {
                LOG_ERROR(TAG, "Motor calibration with error [%s]", ErrorToString(err));
                controller->calibration_state = CalibrationState::ERROR;
            }
            else
            {
                LOG_INFO(TAG, "Motor calibrated");
                controller->calibration_state = CalibrationState::CALIBRATED;
            }
            // disable motor for safety
            if (Error err = controller->disable(); err != Error::None)
            {
                LOG_ERROR(TAG, "Failed to disable motor after calibration. Error [%s]", ErrorToString(err));
            }

            // Restart the control loop (back to normal operation)
            if (wasRunning)
            {
                LOG_DEBUG(TAG, "Restarting control loop");
                if (Error err = Robot::GetInstance().getControlLoop().start(); err != Error::None)
                {
                    LOG_ERROR(TAG, "Failed to start control loop after motor calibration. Error [%s]", ErrorToString(err));
                    return;
                }
            }

            // clean up task handle
            vTaskDelete(nullptr);
        }, "MotorCalib", 4096, this, tskIDLE_PRIORITY + 1, &calibration_task_handle, CORE_BRAIN); err != pdPASS)
    {
        LOG_ERROR(TAG, "Failed to create motor calibration task. Error %d", err);
        return Error::SoftwareFailure;
    }

    return Error::None;
}

Error MotorController::stopCalibration()
{
    if (calibration_state != MotorController::CalibrationState::CALIBRATING)
    {
        return Error::InvalidState;
    }

    if (calibration_task_handle != NULL)
    {
        vTaskDelete(calibration_task_handle);
        deleteCalibrationData(false); // reset calibration data but don't save to NVS
        LOG_WARNING(TAG, "Stopped motor calibration. This could lead to unexpected behavior.");
    }

    return Error::None;
}

Error MotorController::setCalibrationData(CalibrationData& data, bool save)
{
    calibration_data = data;
    calibration_state = CalibrationState::CALIBRATED;
    if (save)
    {
        if (Error err = save_calibration_data(); err != Error::None)
        {
            return err;
        }
    }
    return Error::None;
}

Error MotorController::deleteCalibrationData(bool save)
{
    calibration_state = CalibrationState::UNCALIBRATED;
    calibration_data.pwm_min = motor_attributes.pwm_min;
    calibration_data.pwm_max = motor_attributes.pwm_max;
    if (save)
    {
        if (Error err = delete_calibration_data(); err != Error::None)
        {
            return err;
        }
    }
    return Error::None;
}

Error MotorController::setCalibrationState(CalibrationState state)
{
    LOG_WARNING(TAG, "Manually changing calibration state to [%d]. This could lead to unexpected behavior.", static_cast<uint8_t>(state));
    calibration_state = state;
    return Error::None;
}
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

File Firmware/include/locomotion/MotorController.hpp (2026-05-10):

#pragma once
#include "drivers/MotorDriver.hpp"
#include "drivers/AnalogDriver.hpp"
#include "common/NVS.hpp"
#include <freertos/FreeRTOS.h>
#include <freertos/task.h>

class MotorController
{
public:
    enum class State : uint8_t
    {
        ENABLED = 1,
        DISABLED = 0,
        ERROR = 2,
    };

    enum class CalibrationState : uint8_t
    {
        UNCALIBRATED = 0,
        CALIBRATING = 1,
        CALIBRATED = 2,
        ERROR = 3,
    };

    struct MotorAttributes
    {
        MotorDriver::Value pwm_min;
        MotorDriver::Value pwm_max;
        bool has_feedback;
    };

    constexpr static MotorAttributes MOTOR_ATTR_MG996R = {
        .pwm_min = MotorDriver::MS_TO_PWM(0.5f), // 0.5us duty cycle
        .pwm_max = MotorDriver::MS_TO_PWM(2.5f), // 2.5us duty cycle
        .has_feedback = true
    };

    constexpr static MotorAttributes MOTOR_ATTR_SG90 = {
        .pwm_min = MotorDriver::MS_TO_PWM(1.0f), // 1.0us duty cycle
        .pwm_max = MotorDriver::MS_TO_PWM(2.0f), // 2.0us duty cycle
        .has_feedback = false
    };

    struct CalibrationData
    {
        MotorDriver::Value pwm_min = 0;
        MotorDriver::Value pwm_max = 0;
        MotorDriver::Value pwm_deadband = 0;
        AnalogDriver::Value feedback_min = 0000;
        AnalogDriver::Value feedback_max = 3300; // default to 0-3.3V range
        AnalogDriver::Value feedback_noise = 0;
        int feedback_latency_ms = 0;
        float max_speed = 0.f; // in progress per second
    };

    MotorController();
    
    MotorController(MotorDriver::Channel motor_channel, AnalogDriver::Channel analog_channel, MotorAttributes attribs = MOTOR_ATTR_MG996R);

    /**
     * @brief Initialize the motor controller.
     * @return Error code indicating success or failure.
     */
    Error init();

    /**
     * @brief Deinitialize the motor controller.
     * @return Error code indicating success or failure.
     */
    Error deinit();

    /**
     * @brief Turns on the motor.
     * @return Error code indicating success or failure.
     */
    Error enable();

    /**
     * @brief Turns off the motor.
     * @return Error code indicating success or failure.
     */
    Error disable();

    /**
     * @brief Starts the calibration process.
     * @return Error code indicating success or failure.
     */
    Error startCalibration();

    /**
     * @brief Stops the calibration process (no saving).
     * @note This method should not be called to save calibration data, it is done automatically on calibration sequence completion.
     * @return Error code indicating success or failure.
     */
    Error stopCalibration();

    /**
     * @brief Get the calibration progress as a ratio (0.0 to 1.0).
     * @return Calibration progress.
     */
    float getCalibrationProgress() const { return calibration_progress; }

    /**
     * @brief Set the calibration state.
     * @param state New calibration state.
     * @return Error code indicating success or failure.
     * @note Should only be used for manual calibration control. 
     */
    Error setCalibrationState(CalibrationState state);

    /**
     * @brief Get the current calibration data
     * @return Current calibration data
     */
    const CalibrationData& getCalibrationData() const { return calibration_data; }

    /**
     * @brief Set the current calibration data
     * @param data The CalibrationData object to set
     * @param save Should the data be saved in NVS for future use
     * @return If the save was successfull or not
     */
    Error setCalibrationData(CalibrationData& data, bool save = true);

    /**
     * @brief Delete the current calibration data (fallback to default)
     * @param save Should the deletion be saved in NVS or not
     * @return If the deletion was successfull or not
     */
    Error deleteCalibrationData(bool save = true);

    /**
     * @brief Set the target position for the motor.
     * @param position Target position as a ratio (0.0 to 1.0).
     * @note An approximate position can be set even if the motor is uncalibrated.
     * @return Error code indicating success or failure.
     */
    Error setTargetPosition(float position);

    /**
     * @brief Get the target position of the motor.
     * @param result Target position as a ratio (0.0 to 1.0).
     * @return Error code indicating success or failure.
     */
    Error getTargetPosition(float& result) const;

    /**
     * @brief Get the current position of the motor.
     * @param result Current position as a ratio (0.0 to 1.0).
     * @return Error code indicating success or failure.
     * @note An approximate position will be returned until the motor is calibrated.
     */
    Error getCurrentPosition(float& result) const;

    /**
     * @brief Get the current state of the motor controller.
     * @return Current state.
     */
    State getState() const { return state; }

    /**
     * @brief Get the current state of calibration.
     * @return Current calibration state.
     */
    CalibrationState getCalibrationState() const { return calibration_state; }

    /**
     * @brief Get the motor channel.
     * @return Motor channel.
     */
    MotorDriver::Channel getMotorChannel() const { return motor_channel; }

    /**
     * @brief Get the analog channel.
     * @return Analog channel.
     */
    AnalogDriver::Channel getAnalogChannel() const { return analog_channel; }

private:
    MotorDriver::Channel motor_channel;
    AnalogDriver::Channel analog_channel;

    MotorAttributes motor_attributes;
    CalibrationData calibration_data;
    CalibrationState calibration_state;
    float calibration_progress;
    
    State state;
    float target_position = 0;
    NVS::Handle* nvshandle_ptr;

    TaskHandle_t calibration_task_handle;

    Error __send_target_position();
    Error save_calibration_data();
    Error delete_calibration_data();
    Error run_calibration_sequence();
};

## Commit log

2026-03-15 Changed ControlLoop workflow to hit constant 200Hz
    Sense -> Plan -> Act architecture is finally well implemented
2026-03-16 WIP 3d models
    [Leg_Bottom.FCStd, Settings.FCStd, Shoulders.FCStd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]
2026-03-30 Fixed minor problems in PCBs files
    [BOM.xlsx, PickAndPlace.xlsx]
2026-03-30 Added clearance in servomotor mount
    [Leg_Top.FCStd]
2026-04-09 Updated CAD files
    [Back.FCStd, Battery.FCStd, Leg_Top.FCStd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]
2026-04-09 [WIP] Added .3mf file for easy printing
    [TNY-360.3mf]
2026-04-11 Added servo screw test piece
    [Settings - ServoScrew.stl]
2026-04-18 Added head visor to .3mf file + fixed details
    [Battery.FCStd, Settings.FCStd, Torso - Bottom.stl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]
2026-04-19 Changed SHouder-Top Screws to 6mm
2026-04-23 Improved & Fixed Ears models
    [Ears - Back L.stl, Ears - Back R.stl, Ears - Deco L.stl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]
2026-04-23 Added Servo tester project
2026-04-28 Fixed minor details in Torso-Bottom model
    [Torso - Bottom.stl, Torso.FCStd]
2026-04-29 Updated drivers
2026-04-29 updated I2C config
2026-04-29 Main PCB - V1.1
    - Switched GPIO48 and GPIO46
    - Added CUPEN capacitor
    - Fixed audio low-pass filter and gain
    - Reduced Wi-Fi antenna EMI in audio
    [BOM.xlsx, PickAndPlace.xlsx]
2026-04-30 Added speaker to BOM
2026-05-08 Used new error handling system everywhere
    [AnalogDriver.cpp, CameraDriver.cpp, ControlLoop.cpp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]
2026-05-10 Switched web dashboard to npm sdk
2026-05-10 [WIP] Started new motor calibration method
2026-05-11 Added Current-Based motor calibration
    + added pca9685 reset on startup
    + fixed IMUDriver struct declaration
    [Body.cpp, MotorControllerCalibration.cpp, MotorDriver.cpp]
2026-05-15 Fixed compilation errors in servo tester
    [LED.cpp, main.cpp]
2026-05-15 Changed motor link in BOM + Added servo pcb sheet
2026-05-16 Changed test board to to a default one
2026-05-21 Fixed grounded detection
2026-05-29 Squashed commit of the following:
    commit e213a806b2085b6394d444a8bc590efd7a0f5f61
    Author: Paul LOISIL <fur.waz06@gmail.com>
    Date: Fri May 29 18:58:35 2026 +0200
    Fixed readme presentation
    commit a762b48703e43e9a5a10e1727daac402e7c08108
    Author: Paul LOISIL <fur.waz06@gmail.com>
    Date: Fri May 29 18:52:15 2026 +0200
    Added clearer links to readme
    commit a8290fafa26232a2c61ac495da833057ca0af606
    Author: Paul LOISIL <fur.waz06@gmail.com>
    Date: Thu May 28 17:47:03 2026 +0200
    Updated PCBs QRCodes
    commit 81563ad7d08ea0afbaef477bd3797e53190ab6d2
    Author: Paul LOISIL <fur.waz06@gmail.com>
    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
    [BOM.xlsx, PickAndPlace.xlsx, Torso - Bottom.stl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]

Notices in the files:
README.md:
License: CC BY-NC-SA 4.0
